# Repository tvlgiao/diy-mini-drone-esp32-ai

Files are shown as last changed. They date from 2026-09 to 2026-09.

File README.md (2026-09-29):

# DIY Mini Drone ESP32 AI

Hướng dẫn trực quan (tiếng Việt) để tự làm một mini drone 4 cánh chạy [ESP-Drone](https://github.com/espressif/esp-drone), có tự cân bằng, giữ độ cao, giữ vị trí trong nhà và camera AI.

**Xem hướng dẫn:** https://tvlgiao.github.io/diy-mini-drone-esp32-ai/

## Nội dung

1. **Chuẩn bị đồ** — danh sách linh kiện, bảng tính cân nặng và thời gian bay
2. **Nối dây** — sơ đồ tương tác, cây nguồn, mạch driver AO3400
3. **Lắp ráp** — mô phỏng 12 bước nhìn từ trên xuống
4. **Cài phần mềm** — ESP-IDF v5.0, menuconfig, nạp firmware
5. **Dạy máy nhìn** — module `ai_uart.c` cho ESP-Drone, sketch XIAO ESP32-S3 bám vật màu, Edge Impulse FOMO
6. **Kết nối và bay** — Wi-Fi, checklist trước khi bay, 6 cấp bay thử, chỉnh PID
7. **Thử động cơ** — mô phỏng bộ trộn motor theo đúng công thức của ESP-Drone

## Phần cứng chính

ESP32-WROOM-32 DevKit · MPU6050 · PMW3901 (SPI) · VL53L1X · motor coreless 8520 · AO3400 · LiPo 1S · buck-boost 3,3 V · XIAO ESP32-S3 Sense

## Lưu ý an toàn

Có hàn điện, pin LiPo và cánh quạt quay nhanh. Trẻ em chỉ làm khi có người lớn hướng dẫn.

Trang là một tệp `index.html` tĩnh, không cần build.

## Giấy phép

Nội dung và mã trong repo này phát hành theo giấy phép [MIT](LICENSE).

Đoạn công thức trộn động cơ trong tab "Thử động cơ" trích từ [ESP-Drone](https://github.com/espressif/esp-drone) (`power_distribution_stock.c`), thuộc giấy phép GPL-3.0 của dự án đó. Module `ai_uart.c` được thiết kế để biên dịch cùng ESP-Drone, nên firmware sau khi build tuân theo GPL-3.0.

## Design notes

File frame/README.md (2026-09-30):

# Khung carbon 120 mm cho motor 8520

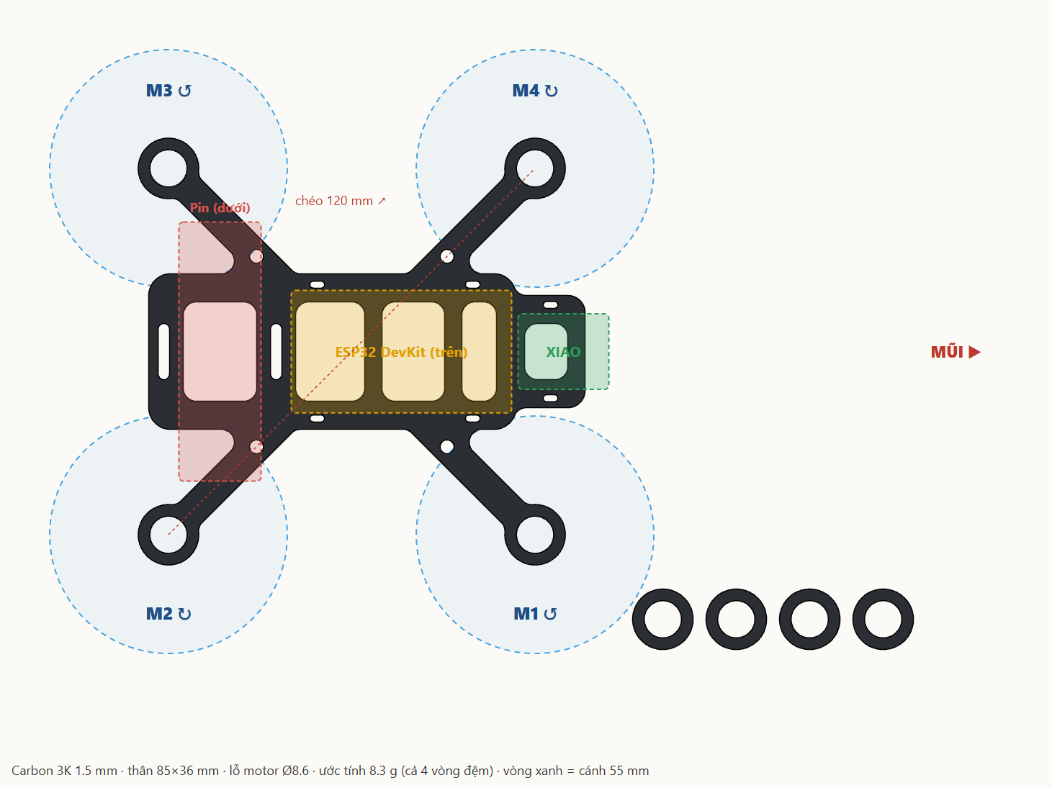
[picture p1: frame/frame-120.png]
Khung


- `frame-120.dxf` — gửi xưởng cắt CNC. Đơn vị mm, layer `CUT`, gồm khung + 4 vòng đệm motor.
- Vật liệu: tấm carbon 3K dày **1,5 mm**. Dao phay 1 mm. Nặng khoảng 8,3 g.
- Motor 8520: quấn 1 lớp gen co nhiệt quanh thân rồi ấn vào lỗ Ø8,6 mm. Dán vòng đệm dưới vành để phần ôm cao 3 mm.
- Cánh 55 mm. Nhìn từ trên: M1 trước phải ↺, M2 sau phải ↻, M3 sau trái ↺, M4 trước trái ↻.
- Đổi thông số (chéo, độ dày, lỗ motor): sửa đầu file `make_frame.py` rồi chạy `python make_frame.py` (cần `pip install shapely ezdxf`).

Bụi carbon độc: cắt, mài phải đeo khẩu trang, làm ướt khi mài.

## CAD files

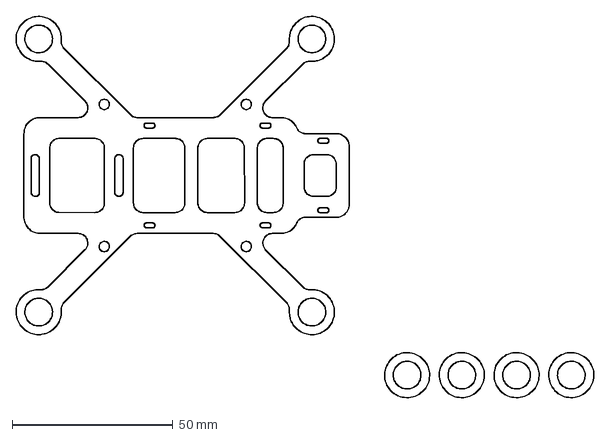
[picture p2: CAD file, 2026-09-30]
frame/frame-120.dxf
179.4 x 118.4 mm

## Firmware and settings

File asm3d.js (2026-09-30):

/*
 * Mô phỏng lắp ráp 3D cho Mini Drone ESP32 AI.
 * Script thường (không phải module) để chạy được cả khi mở index.html bằng file://;
 * three.js tải bằng import() động từ jsDelivr (+esm: OrbitControls dùng chung bản three).
 * Dùng: const sim = window.initAsm3D(divEl); sim.setStep(i)   // i = 0..11 theo STEPS
 * Đơn vị: mm. Hệ trục máy bay: X mũi, Y trái, Z lên  →  three: (x, z, -y).
 * File này sinh ra từ src/asm3d.src.js bằng src/build-asm3d.py (nhúng frame/frame-120.json).
 */
(function () {
  'use strict';
  const FRAME = {"frame":{"outer":[[-43.26,-35.48],[-41.24,-35.43],[-40.66,-35.29],[-40.12,-35.04],[-39.64,-34.68],[-28.07,-23.12],[-27.66,-22.6],[-27.37,-22.01],[-27.21,-21.37],[-27.21,-20.71],[-27.42,-19.85],[-27.87,-19.1],[-28.59,-18.47],[-29.39,-18.11],[-30.12,-18.0],[-41.99,-18.0],[-42.75,-17.94],[-43.82,-17.66],[-44.86,-17.1],[-45.69,-16.37],[-46.36,-15.45],[-46.82,-14.32],[-47.0,-13.1],[-47.0,12.99],[-46.85,14.23],[-46.4,15.37],[-45.69,16.37],[-44.76,17.17],[-43.67,17.71],[-42.96,17.91],[-42.14,18.0],[-30.19,18.0],[-29.54,18.07],[-28.59,18.47],[-28.12,18.83],[-27.78,19.21],[-27.32,20.13],[-27.21,20.63],[-27.2,21.22],[-27.42,22.15],[-27.97,23.01],[-39.75,34.78],[-40.3,35.14],[-40.99,35.38],[-43.44,35.5],[-44.31,35.69],[-45.12,35.97],[-46.01,36.41],[-46.75,36.92],[-47.48,37.59],[-48.04,38.24],[-48.69,39.3],[-49.17,40.54],[-49.39,41.76],[-49.39,43.09],[-49.17,44.31],[-48.69,45.56],[-48.04,46.61],[-47.14,47.6],[-46.19,48.33],[-45.09,48.9],[-43.81,49.29],[-42.62,49.42],[-41.38,49.35],[-40.21,49.07],[-38.99,48.53],[-37.97,47.83],[-37.34,47.24],[-36.79,46.58],[-36.33,45.86],[-35.9,44.96],[-35.64,44.15],[-35.48,43.3],[-35.39,41.02],[-35.14,40.31],[-34.73,39.69],[-13.88,18.83],[-13.41,18.47],[-12.89,18.2],[-12.32,18.04],[-11.81,18.0],[11.88,18.0],[12.54,18.09],[13.16,18.32],[13.93,18.88],[34.78,39.75],[35.17,40.37],[35.38,40.99],[35.48,43.3],[35.64,44.15],[35.9,44.96],[36.33,45.86],[36.79,46.58],[37.34,47.24],[37.97,47.83],[38.99,48.53],[40.25,49.08],[41.59,49.38],[42.92,49.41],[44.15,49.21],[45.44,48.75],[46.58,48.06],[47.6,47.14],[48.33,46.19],[48.9,45.09],[49.29,43.81],[49.42,42.62],[49.35,41.38],[49.07,40.21],[48.59,39.11],[47.93,38.11],[47.27,37.37],[46.61,36.82],[45.86,36.33],[45.09,35.95],[44.28,35.68],[43.44,35.5],[41.02,35.39],[40.38,35.18],[39.75,34.78],[27.97,23.01],[27.62,22.54],[27.39,22.08],[27.25,21.59],[27.19,21.0],[27.32,20.13],[27.66,19.4],[28.23,18.73],[28.98,18.26],[29.97,18.01],[33.75,17.94],[34.78,17.67],[35.69,17.21],[36.37,16.69],[36.95,16.06],[37.36,15.45],[37.83,14.49],[38.18,14.0],[38.67,13.56],[39.26,13.23],[39.82,13.06],[40.34,13.0],[50.01,13.0],[50.86,12.91],[51.87,12.54],[52.74,11.91],[53.42,11.07],[53.83,10.14],[54.0,9.01],[54.0,-9.18],[53.91,-9.86],[53.73,-10.46],[53.42,-11.07],[53.02,-11.63],[52.48,-12.14],[51.87,-12.54],[51.18,-12.82],[50.47,-12.97],[40.34,-13.0],[39.4,-13.18],[38.81,-13.47],[38.24,-13.94],[37.84,-14.47],[37.36,-15.45],[36.93,-16.09],[36.28,-16.77],[35.59,-17.28],[34.7,-17.7],[33.72,-17.95],[30.05,-18.0],[29.04,-18.23],[28.41,-18.59],[27.83,-19.15],[27.42,-19.85],[27.21,-20.63],[27.2,-21.22],[27.32,-21.87],[27.58,-22.48],[27.97,-23.01],[39.69,-34.73],[40.3,-35.14],[40.99,-35.38],[43.44,-35.5],[44.31,-35.69],[45.12,-35.97],[46.01,-36.41],[46.75,-36.92],[47.48,-37.59],[48.06,-38.27],[48.75,-39.42],[49.18,-40.58],[49.41,-41.89],[49.39,-43.13],[49.13,-44.44],[48.69,-45.56],[48.04,-46.61],[47.14,-47.6],[46.16,-48.35],[44.96,-48.95],[43.77,-49.3],[42.58,-49.42],[41.25,-49.33],[40.09,-49.02],[38.96,-48.51],[37.87,-47.74],[37.25,-47.14],[36.71,-46.47],[36.26,-45.74],[35.9,-44.96],[35.64,-44.15],[35.48,-43.3],[35.39,-41.02],[35.14,-40.31],[34.73,-39.69],[13.88,-18.83],[13.09,-18.29],[12.25,-18.03],[-11.88,-18.0],[-12.61,-18.11],[-13.29,-18.39],[-13.93,-18.88],[-34.78,-39.75],[-35.17,-40.37],[-35.4,-41.07],[-35.48,-43.26],[-35.83,-44.77],[-36.5,-46.16],[-37.37,-47.27],[-38.55,-48.26],[-39.92,-48.96],[-41.42,-49.35],[-42.96,-49.41],[-44.31,-49.17],[-45.59,-48.67],[-46.75,-47.93],[-47.74,-46.98],[-48.53,-45.86],[-49.08,-44.6],[-49.38,-43.26],[-49.41,-41.89],[-49.17,-40.54],[-48.67,-39.26],[-47.93,-38.11],[-46.98,-37.11],[-45.86,-36.33],[-44.6,-35.77]],"holes":[[[-38.14,-42.74],[-38.16,-41.9],[-38.34,-41.08],[-38.69,-40.31],[-39.17,-39.62],[-39.78,-39.04],[-40.49,-38.59],[-41.28,-38.28],[-42.11,-38.14],[-42.95,-38.16],[-43.78,-38.34],[-44.55,-38.69],[-45.24,-39.17],[-45.82,-39.78],[-46.27,-40.49],[-46.57,-41.28],[-46.71,-42.11],[-46.69,-42.95],[-46.51,-43.78],[-46.17,-44.55],[-45.68,-45.24],[-45.07,-45.82],[-44.36,-46.27],[-43.57,-46.57],[-42.74,-46.71],[-41.9,-46.69],[-41.08,-46.51],[-40.31,-46.17],[-39.62,-45.68],[-39.04,-45.07],[-38.59,-44.36],[-38.28,-43.57]],[[-20.47,-22.18],[-20.54,-21.56],[-20.85,-21.02],[-21.34,-20.63],[-21.94,-20.47],[-22.56,-20.54],[-23.11,-20.85],[-23.49,-21.34],[-23.66,-21.94],[-23.58,-22.56],[-23.27,-23.11],[-22.78,-23.49],[-22.18,-23.66],[-21.56,-23.58],[-21.02,-23.27],[-20.63,-22.78]],[[-7.04,-14.7],[-8.92,-14.7],[-9.22,-14.77],[-9.48,-14.95],[-9.65,-15.21],[-9.7,-15.52],[-9.63,-15.82],[-9.39,-16.13],[-9.02,-16.29],[-7.08,-16.3],[-6.78,-16.23],[-6.39,-15.88],[-6.31,-15.36],[-6.56,-14.91]],[[-44.79,5.33],[-44.79,-5.36],[-44.63,-5.84],[-44.3,-6.22],[-43.85,-6.45],[-43.34,-6.49],[-42.94,-6.38],[-42.58,-6.12],[-42.32,-5.76],[-42.21,-5.33],[-42.21,5.36],[-42.35,5.81],[-42.65,6.18],[-43.03,6.41],[-43.5,6.5],[-43.97,6.41],[-44.37,6.16],[-44.66,5.78]],[[-36.22,-11.49],[-24.71,-11.49],[-24.06,-11.35],[-23.4,-11.03],[-22.83,-10.57],[-22.39,-9.98],[-22.11,-9.3],[-22.0,-8.57],[-22.0,8.65],[-22.13,9.37],[-22.43,10.04],[-22.93,10.67],[-23.52,11.11],[-24.2,11.39],[-24.93,11.5],[-36.22,11.49],[-36.94,11.35],[-37.6,11.03],[-38.17,10.57],[-38.61,9.98],[-38.89,9.3],[-39.0,8.57],[-38.98,-8.87],[-38.68,-9.85],[-38.07,-10.67],[-37.22,-11.24]],[[-18.8,5.3],[-18.79,-5.36],[-18.63,-5.84],[-18.3,-6.22],[-17.85,-6.45],[-17.34,-6.49],[-16.92,-6.36],[-16.58,-6.12],[-16.32,-5.76],[-16.21,-5.33],[-16.21,5.36],[-16.35,5.81],[-16.65,6.18],[-17.06,6.42],[-17.53,6.5],[-18.0,6.4],[-18.4,6.14],[-18.68,5.76]],[[-10.15,-11.5],[0.37,-11.48],[1.08,-11.3],[1.73,-10.95],[2.27,-10.46],[2.68,-9.85],[2.91,-9.23],[3.0,-8.57],[2.99,8.72],[2.82,9.51],[2.49,10.17],[2.01,10.72],[1.35,11.18],[0.73,11.41],[0.07,11.5],[-10.29,11.49],[-11.01,11.32],[-11.67,10.99],[-12.27,10.46],[-12.68,9.85],[-12.91,9.23],[-13.0,8.57],[-12.98,-8.87],[-12.68,-9.85],[-12.07,-10.67],[-11.22,-11.24],[-10.66,-11.43]],[[9.85,-11.5],[18.94,-11.47],[19.65,-11.27],[20.29,-10.91],[20.87,-10.35],[21.24,-9.72],[21.43,-9.16],[21.5,-8.57],[21.49,8.72],[21.32,9.51],[20.95,10.23],[20.4,10.82],[19.72,11.24],[19.16,11.43],[18.57,11.5],[9.63,11.48],[8.85,11.27],[8.21,10.91],[7.63,10.35],[7.26,9.72],[7.07,9.16],[7.0,8.57],[7.02,-8.87],[7.32,-9.85],[7.93,-10.67],[8.78,-11.24],[9.34,-11.43]],[[-7.02,16.3],[-8.92,16.3],[-9.21,16.24],[-9.47,16.07],[-9.64,15.81],[-9.7,15.5],[-9.64,15.19],[-9.39,14.87],[-9.02,14.71],[-7.08,14.7],[-6.79,14.76],[-6.4,15.11],[-6.31,15.62],[-6.55,16.08]],
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

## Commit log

2026-09-29 Add visual DIY mini drone ESP32 AI guide
    Single-page Vietnamese guide for kids: parts list, interactive wiring
    diagram, assembly simulation, ESP-Drone firmware setup, XIAO ESP32-S3
    AI tracking over UART, first-flight levels and motor mixer simulator.
2026-09-29 Add part illustrations, tools list, buy links, rotation arrows
    - Illustrated parts and tools tables with Vietnam store links
    - Rotation arrows and prop A/B labels matching the official ESP-Drone photo
    - Clarify MPU6050 axis and PMW3901 drift check; power-on self-test note
2026-09-29 Link official ESP-Drone rotation photo in assembly steps
2026-09-29 Fix spin animation direction cues
    Dashed highlight rings on CCW motors now march counter-clockwise, blade
    tips carry a marker, and props spin slower so the direction is readable.
2026-09-30 Add CNC carbon frame (120 mm, 8520 motors)
    DXF + preview + generator script for a 1.5 mm carbon unibody frame
    that can be cut locally in Vietnam; BOM, weight and motor step updated.
    [frame-120.dxf]
2026-09-30 Lighten carbon frame to 8.3 g, add frame drawing to the guide
    Five lightening windows (ribs >= 2.7 mm) cut the frame from 10.7 g to
    8.3 g. The parts tab now shows the drawing with DXF download, full-size
    SVG and cutting notes.
    [frame-120.dxf]
2026-09-30 Fix BOM against live listings, add how-to figures for every step
    - Motor shaft is 1 mm: props now 55 mm / 1 mm hole, sold as A+B pairs
    - ESP32 link replaced (old seller on vacation), pick CH340 Type-C with cable
    - PMW3901 only ships from abroad; XIAO price updated; LiPo must be a drone pack
    - Carbon sheet 1.5 mm price, battery strap and CNC cutting rows added
    - Through-hole 1000 uF capacitor; weights use measured motor 6 g, pack 13.5 g
    - Price column renamed to line total
    - Each assembly step shows 2-4 close-up panels (heat-shrink motor mount,
    MOSFET pinout and one-channel schematic, polarity, strap, sensor layout)
2026-09-30 Add 3D assembly viewer, stand XIAO upright at the nose
    The assembly tab now opens a three.js model of the carbon build that
    animates each step (heat-shrink motor mount close-up, bottom view for
    battery and sensors, spinning props with correct directions). 2D view
    remains one click away. XIAO Sense must stand upright for the camera to
    face forward; step text and figure updated.
    [frame-120.dxf]
2026-09-30 Redraw 2D assembly view from the carbon frame outline
    Frame shape comes from frame-120.json at true scale; battery sits
    across the tail between the strap slots, motor driver at the rear,
    XIAO stands upright at the nose, sensors on the underside.
2026-09-30 Every BOM row now links to one exact product page
    - Battery: DOGCOM 450 mAh 1S PH2.0 from MoodFPV (old Shopee seller closed)
    - Charger: TP4056 USB-C board (Hshop) + PH2.0 lead; buck-boost 3.3 V from icdayroi
    - Search links replaced with product pages on icdayroi, Hshop, Tiki, Lazada
    - Combined rows split: resistors, ceramic caps, LEDs, SOT-23 adapters,
    electrical tape and foam tape each get their own row and link
2026-09-30 Note: fly levels 1-4 without the PMW3901, fit it later
    Firmware only logs a warning when the flow sensor is missing
    (deckTest is disabled in system.c), so the build can fly while the
    imported sensor is still in transit.
2026-09-30 Switch battery to BetaFPV 450 mAh BT2.0 (HCM seller)
    BOM, weight (12.7 g), connector rows, step figure, 2D and 3D battery
    size (67 x 12 x 6 mm) updated; BT2.0 jacks from MoodFPV, polarity
    checked with a meter before soldering.
2026-09-30 BT2.0 jack: rc910 (HCM) on Shopee, ESC-side variant
2026-09-30 Battery link: VchannelStore (HCM), same BetaFPV 450 mAh BT2.0 pack
2026-09-30 Battery link: Vchannel website (HCM showroom), not Shopee
